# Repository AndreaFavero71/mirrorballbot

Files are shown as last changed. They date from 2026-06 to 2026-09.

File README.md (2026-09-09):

# MirrorBallBot

An open-source ball-balancing robot that sees through a mirror.<br><br>
MirrorBallBot keeps a ball centred on a circular platform by tilting it with three stepper motors.<br>
You can control the ball with your finger on a touchscreen, record paths, or let it auto-balance.<br>
MirrorBallBot is fully open-source:
 - two instruction manuals (QuickStartGuide and Reference Manual)
 - stl and step files
 - code

<br><br>
## Demo videos
https://youtu.be/ORftNl7bZG4<br><br>
Watch the Demo (https://youtu.be/ORftNl7bZG4)

<br><br>
https://youtu.be/C2Nf5jWF-SY<br><br>
Watch the Demo (https://youtu.be/C2Nf5jWF-SY)

<br><br>
Fully 3D printable version (smaller footprint):<br>
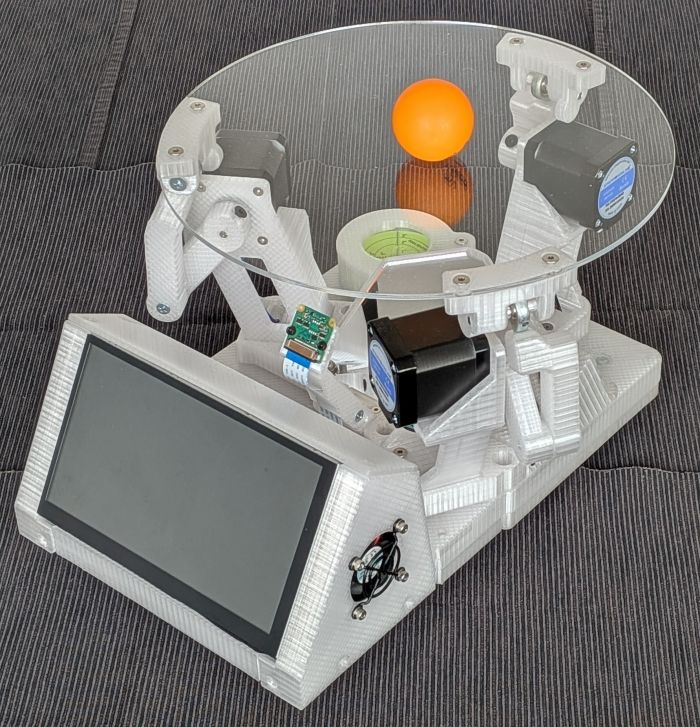
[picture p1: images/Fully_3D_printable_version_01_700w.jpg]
title image
 

<br><br>
## Key innovations
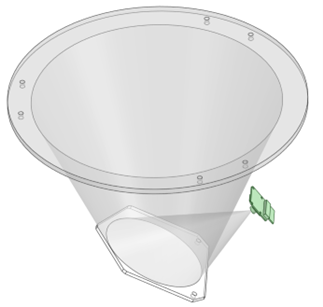
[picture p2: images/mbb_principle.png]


1. **Vision system**: Unlike most designs, it uses side-mounted camera pointing at a mirror (inclined 27°).
By considering the same camera and same robot height, the mirror concept increases the Field of View by 58%.
This allows for a larger platform while keeping the robot compact.

2. **Finger follower**: The ball follows, in real time, the finger's position on the touchscreen.

<br><br>
## Features

- **Two versions available:** Wooden base or fully 3D-printable.
- **Touchscreen GUI:** 7" DSI display with full control interface.
- **Real-Time Video Feed:** Live camera images displayed directly on screen.
- **Autonomous Auto-Balance:** Keeps the ball centred.
- **Finger-Follow Mode:** Drag your finger across the screen to guide the ball.
- **Predefined Paths:** Execute geometric patterns (Square, Circle, Infinity, Triangle, Line).
- **Record & Replay:** Draw custom paths with your finger to record and loop them.
- **Interactive PID Tuning:** Adjust control loop parameters via the GUI in real time.
- **Automatic HSV Calibration:** Instantly adapts to different ball colours and ambient lighting.
- **Sensorless Homing:** Uses TMC2209 StallGuard, no physical limit switches required.
- **Active Thermal Management:** PWM controlled cooling fans with automated temperature monitoring.

<br><br>
## How It Works
1. **Detection**: The camera looks at a mirror placed underneath the transparent platform, detects the ball via HSV thresholding, the ball position is retrieved. This flow works at more than 110 FPS.
2. **Calculation**: The ball position is compared to the target, and via a PID controller the new platform angle is calculated.
3. **Communication**: The Raspberry Pi 4 sends the information (speed and number of steps) to the three RP2040-Zero, via a custom I2C protocol.
4. **Actuation**: The three RP2040-Zero decode the I2C command to speed, direction and number of steps, and load them into the PIO buffer. Finally, the steppers move the platform. The platform actuation works at 17~25Hz.

<br><br>
### Architecture Overview
 - **Raspberry Pi 4:** Vision processing, PID control, GUI, and I2C Master.
 - **3x RP2040-Zero:** Motion execution, I2C Slaves, and hardware-precise PIO step generation.
 - **3x TMC2209:** Silent stepper drivers configured for Sensorless homing.
 - **3x NEMA17:** Stepper motors executing the platform tilts.

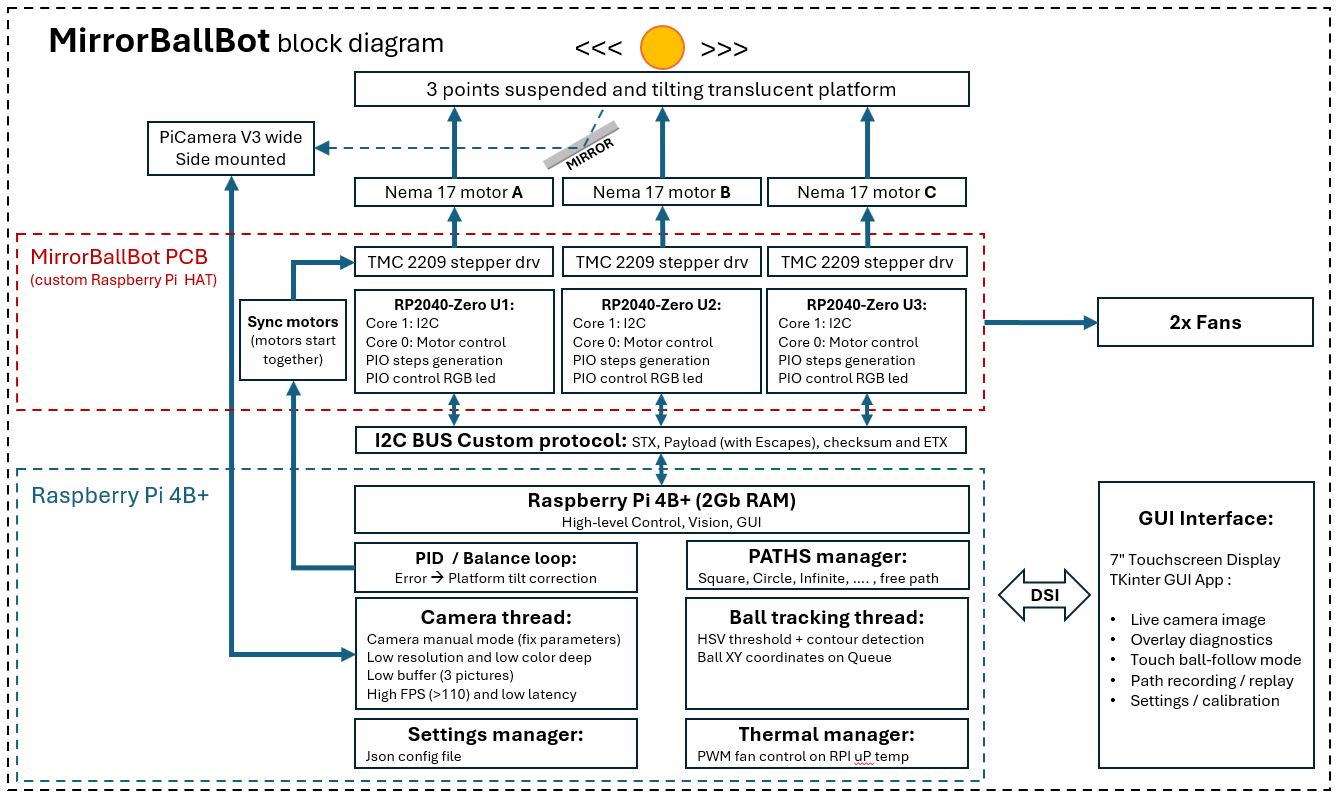
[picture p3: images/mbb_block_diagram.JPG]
block_diagram


<br><br>
## Hardware Requirements
| Component | Qty |
|---|-----|
| Raspberry Pi 4 2GB (1Gb is sufficient) | 1 |
| RP2040-Zero | 3 |
| TMC2209 stepper driver | 3 |
| NEMA17 stepper motor | 3 |
| PiCamera 3 Wide | 1 |
| 7" DSI touchscreen (800x480)| 1 |
| MirrorballBot custom PCB | 1 |
| XL4015 step-down converter | 1 |
| 20V 5A power supply | 1 |

> **Looking for the full Bill of Materials?** A comprehensive, itemized BOM with all the components and raw material specs is available in the full documentation.

<br><br>
## Documentation
The [Quick Start Guide](https://github.com/AndreaFavero71/mirrorballbot/blob/main/doc/MirrorBallBot_QuickStartGuide.pdf) provides the essential information to build the robot, as a PDF file of approx. 50 pages.<br>

The [Reference Manual](https://github.com/AndreaFavero71/mirrorballbot/blob/main/doc/MirrorBallBot_ReferenceManual.pdf) provides detailed information, yet the **~170 page PDF file** could intimidate at first glance. It provides exhaustive coverage of:
- BOM
- Wooden base or fully 3D printable version.
- 3D printing and acrylic laser cutting.
- PCB assembly & soldering maps (250+ pads).
- Detailed step-by-step mechanical assembly (36 steps with photos).
- Software environment setup and configuration parameters.
- GUI operation, PID tuning, and troubleshooting/QA.<br><br>

| Manual | Best for |
| :--- | :--- |
| **Quick Start Guide** | Most makers. It's concise, action-oriented, and will get you from zero to a working robot with minimal friction. |
| **Reference Manual** | When you want to understand *why* something works, encounter an issue not covered in the Quick Start Guide, or are curious about the design process, custom I2C protocol, or PID controller theory. |

**Recommendation:** Start with the Quick Start Guide. Follow the steps, and refer to the Reference Manual only when you need more detail.<br><br>
**Download the manuals from the [`/doc`](https://github.com/AndreaFavero71/mirrorballbot/blob/main/doc/) folder:**
- [Quick Start Guide (~50 pages)](https://github.com/AndreaFavero71/mirrorballbot/blob/main/doc/MirrorBallBot_QuickStartGuide.pdf)
- [Reference Manual (~170 pages)](https://github.com/AndreaFavero71/mirrorballbot/blob/main/doc/MirrorBallBot_ReferenceManual.pdf)

<br><br>
## Quick Start (for experienced makers)

1. Decide if wooden base or fully 3D-printed version. If wooden, CNC or route the base.
2. 3D print all parts (0.2mm layer, 30% infill, no supports, suggested PETG).
3. Laser cut acrylic (translucent plate + mirror).
4. Assemble the MirrorBallBot PCB (250+ solder pads).
5. Flash each RP2040-Zero with **MicroPython v1.24 Pimoroni Tiny2040** uf2 firmware (https://micropython.org/download/PIMORONI_TINY2040/).
6. Copy the MicroPython file to the RP2040-Zero boards (files at https://github.com/AndreaFavero71/mirrorballbot/tree/main/rp2040).
7. Set up the Raspberry Pi:
     - Flash a 32-bit Desktop OS (Trixie, or Bookworm) into a microSD.
      ```
      git clone https://github.com/AndreaFavero71/mirrorballbot.git
      cd mirrorballbot/src
      bash mbb_install.sh
      ```
8. Set the XL4015 voltage (OUT+) to 5.1V.
9. Set the drivers **Vref** according to the steppers' rated current.
10. Run first tests before full assembly; This includes checking the motor direction (it can be reversed via a settings in mbb_settings.json).
11. Full assembly following the step-by-step guide.
12. Calibrations:
     - Camera inclination (centre the camera view to the platform centre).
     - Sensorless homing calibration.
     - Ball colour calibration.
     - PID tuning.
13. Enjoy the robot!
14. Provide feedback :smile:

<br><br>
## First Run
After assembly, place the ball on the middle of the platform, and start the GUI via a Graphical Remote Desktop Client, like VNCViewer:
  ```
  cd ~/mirrorballbot/src
  python3 mbb_gui.py
  ```

Differently, just tap the MirrorBallBot icon on the 7-inch Raspberry Pi Desktop (the icon got automatically installed on the desktop, thanks to the mbb_install.sh).<br>

The GUI will open on the touchscreen.<br>
Auto-Balance should already be active, and the robot will start balancing the ball.<br>
If the ball is not wrapped by a green contour, set an indicative ball size and run the AUTO calibration for the colors.<br>

<br><br>
## Tools You'll Need
- 3D printer (Minimum 210x210 mm bed capacity).
- Laser cutter or CNC (for acrylic parts; commercial laser-cutting services work great).
- Hand router or CNC (for carving wire channels in the wood base), unless you prefer the fully 3D printable version.
- Soldering iron and basic electronics assembly tools.
- Multimeter (essential for driver Vref tuning).
- Screwdrivers and ball-end Allen keys.
- Computer with SD card reader.
- Solid foundational skills in DIY mechatronics and Python scripting.

<br><br>
## Sponsors
MirrorBallBot has been designed as an open-source project. This means I purchased most of the parts myself, just as anyone else would, and invested a considerable amount of time to make a fairly complex robot as easy as possible to reproduce.

I also greatly appreciate companies that support my hobby, by providing parts or services free of charge. The companies below generously sponsored components used in the MirrorBallBot project:
- Thanks to **PCBWay** for sponsoring the MirrorBallBot PCB [https://www.pcbway.com/]
- Thanks to **ELECROW** for sponsoring the 7" DSI touchscreen [https://www.elecrow.com/7-inch-800-480-dsi-display-touch-screen-with-bracket-compatible-with-raspberry-pi.html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]

I would also like to thank ELECROW and PCBWay for believing in this project. They both offered their support when MirrorBallBot was still just an idea, with no guarantee that it would ever reach the stage of becoming a published project.

<br><br>
## Credits
Credits to **danjperron** for his low-level I2C driver for RP2040, found at the Raspberry Pi forum (https://forums.raspberrypi.com/viewtopic.php?t=302978&start=50), from which I've derived the one used in this project.

<br><br>
## Feedback
If you decide to build your own MirrorBallBot, I would love to hear about it! Please open an issue, share your build photos, or submit feedback to let me know how your robot turned out.

<br><br>
## License
MIT License
[License: MIT](https://opensource.org/licenses/MIT) | [Python 3.9+](https://www.python.org/) | [MicroPython 1.24](https://micropython.org/)

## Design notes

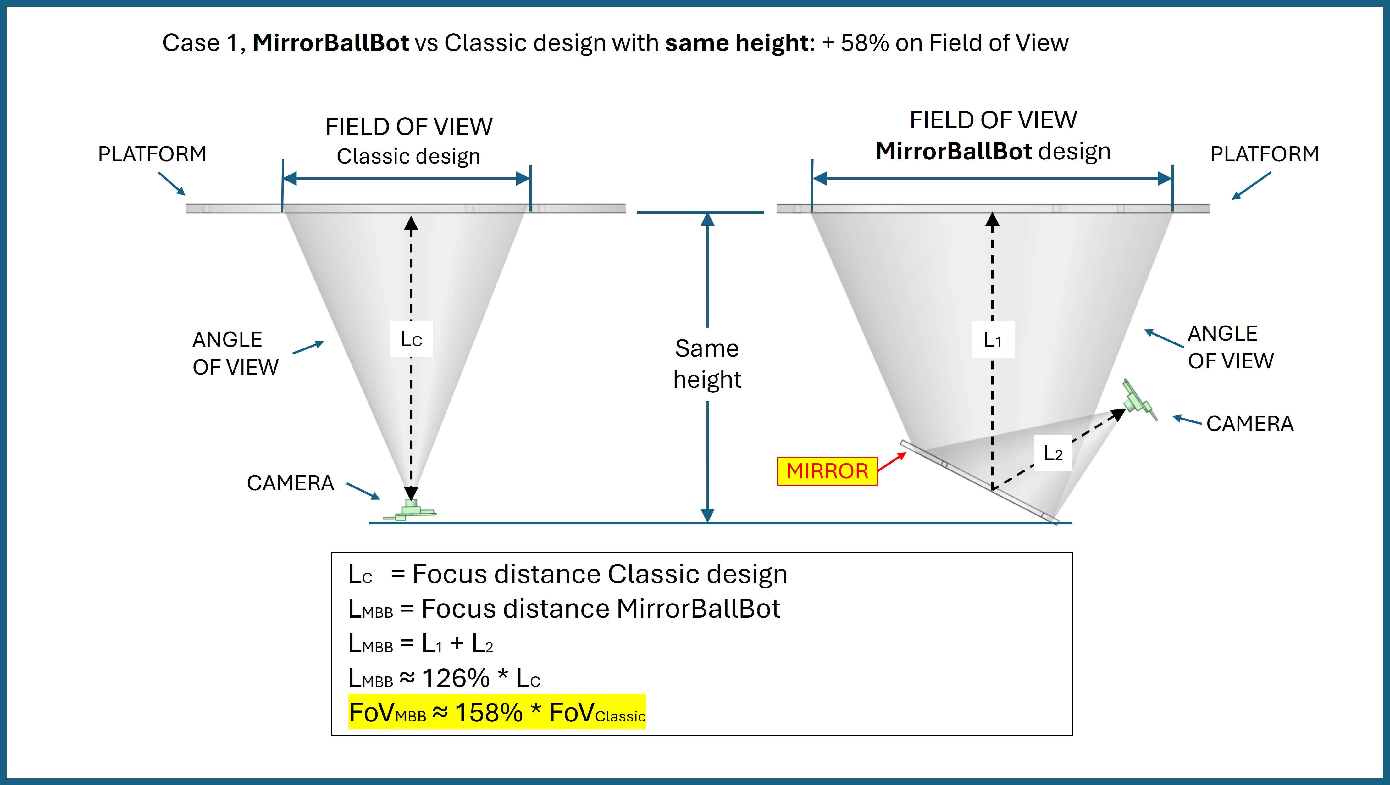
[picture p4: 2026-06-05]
images/Same_height_larger_FoV.jpg

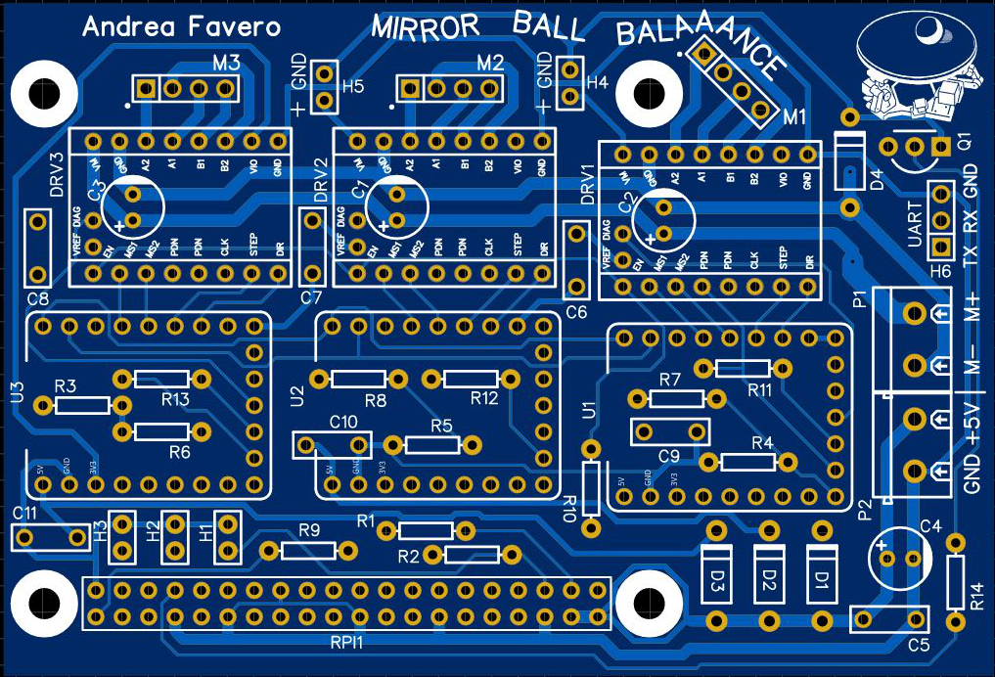
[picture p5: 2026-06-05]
board/Top_side.JPG

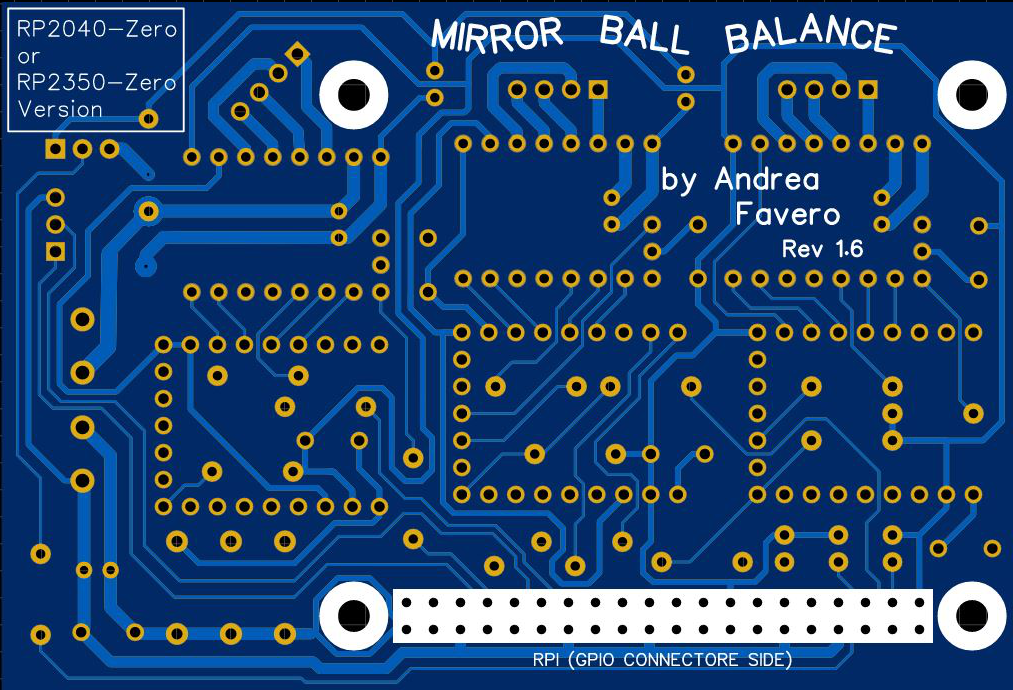
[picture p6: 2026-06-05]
board/Bottom_side.JPG

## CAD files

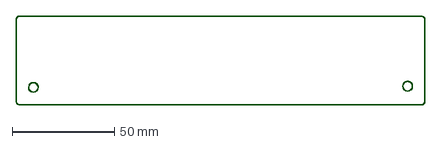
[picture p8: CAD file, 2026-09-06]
3d_models/fully_3d_printable/dxf/PCB_cover_3mm_thick.dxf
199.9 x 43.5 mm

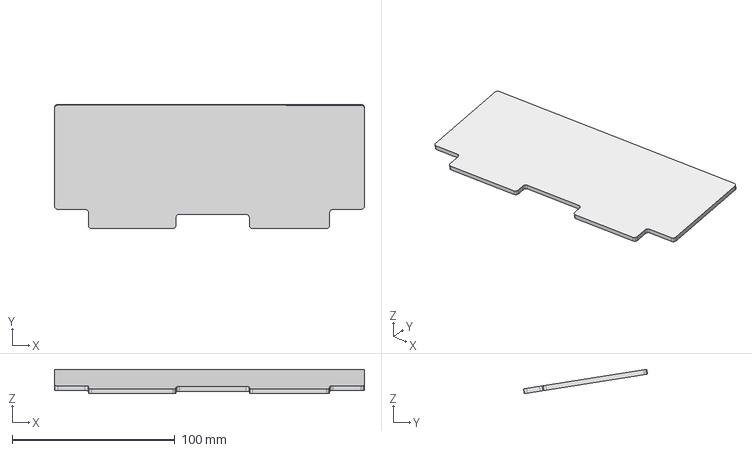
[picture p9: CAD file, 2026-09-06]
3d_models/fully_3d_printable/step/PCB_back_cover.stp
190.4 x 76.3 x 15.0 mm

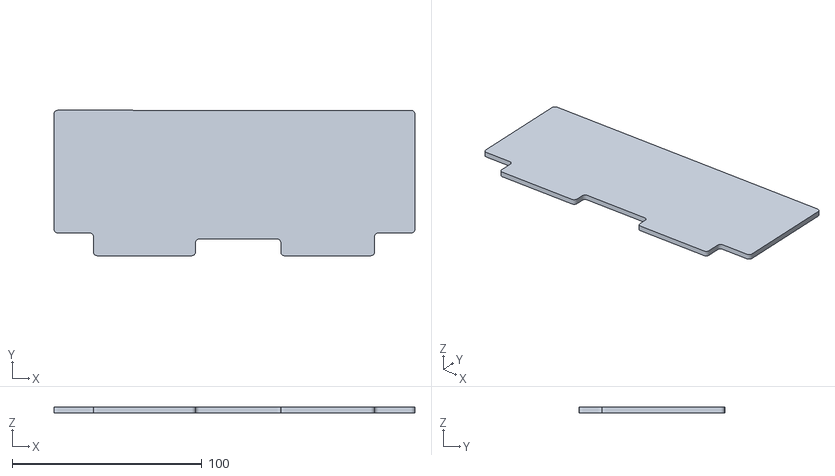
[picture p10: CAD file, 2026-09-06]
3d_models/fully_3d_printable/stl/PCB_back_panel.stl
190.4 x 76.8 x 3.00

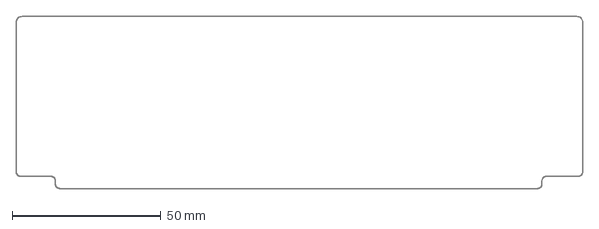
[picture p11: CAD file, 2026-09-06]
3d_models/wooden_base/dxf/PCB_back_cover_3mm_thick.dxf
190.4 x 57.8 mm

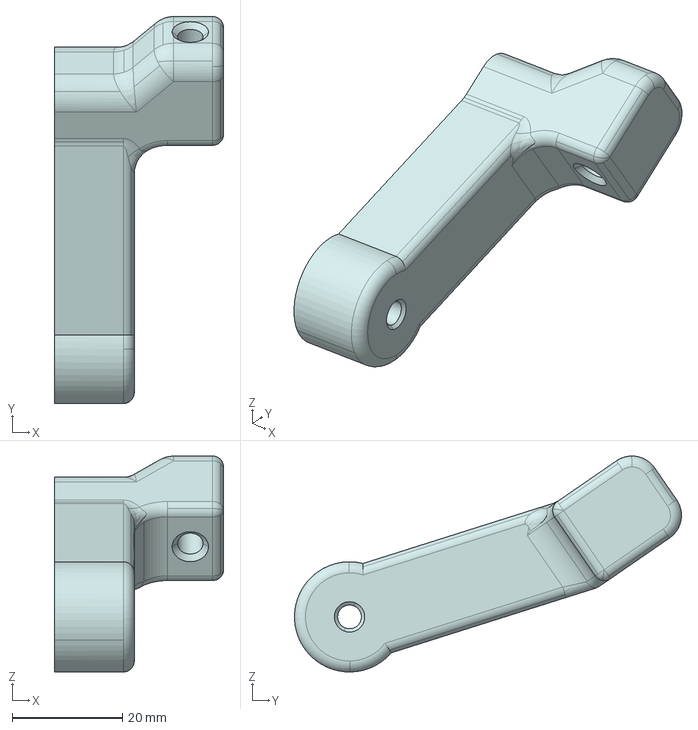
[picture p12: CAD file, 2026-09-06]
3d_models/wooden_base/step/Arm_2.stp
30.7 x 70.2 x 39.2 mm

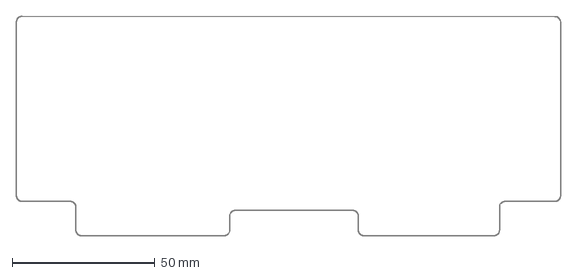
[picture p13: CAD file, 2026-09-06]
3d_models/fully_3d_printable/dxf/PCB_back_cover_3mm_thick.dxf
190.4 x 76.8 mm

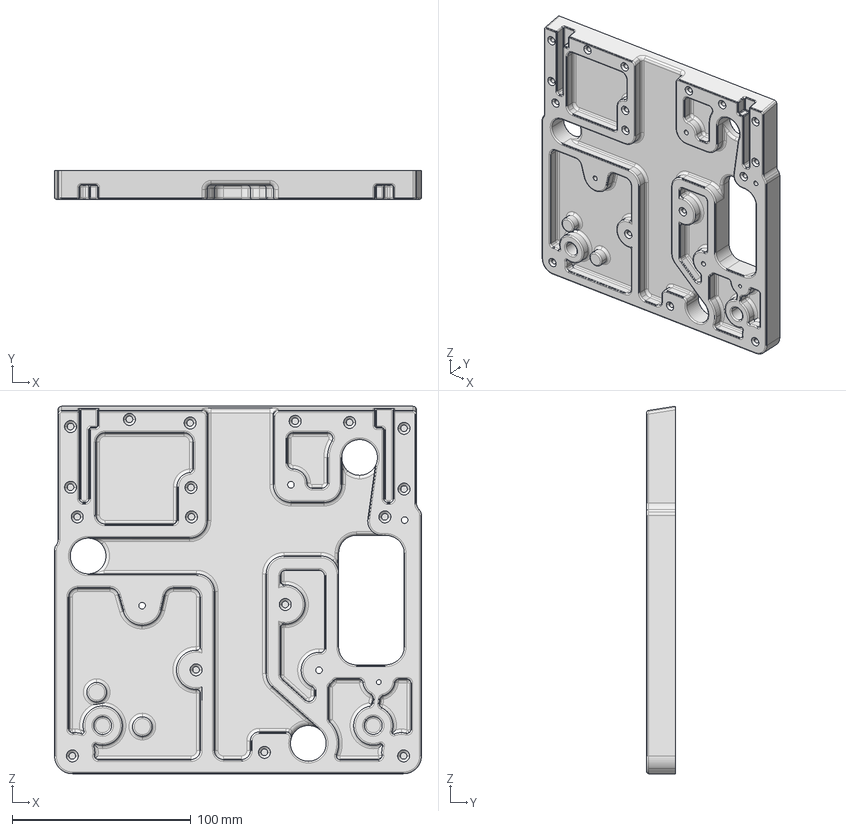
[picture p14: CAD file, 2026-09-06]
3d_models/fully_3d_printable/step/Base_top.stp
205.6 x 16.0 x 205.9 mm

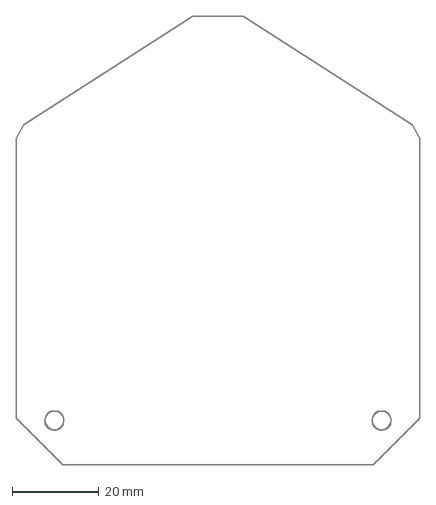
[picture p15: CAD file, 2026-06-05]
3d_models/wooden_base/dxf/Mirror.dxf
93.0 x 103.4 mm

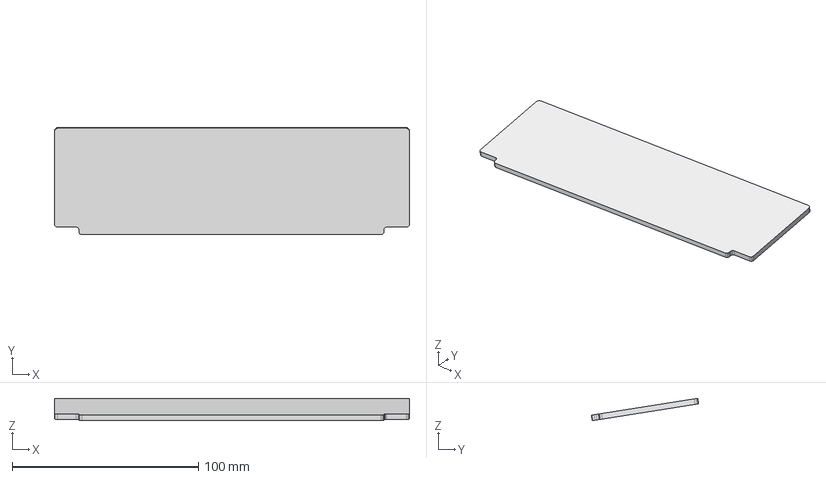
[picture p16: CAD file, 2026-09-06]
3d_models/wooden_base/step/PCB_back_cover.stp
190.4 x 57.6 x 12.0 mm

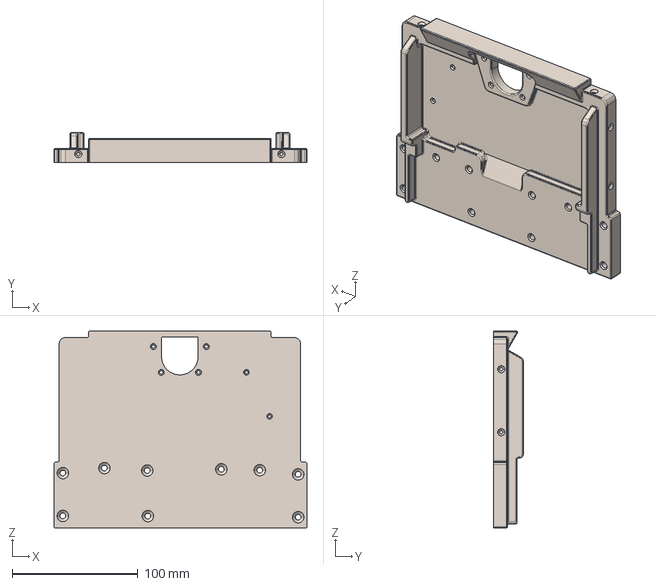
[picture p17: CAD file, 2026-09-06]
3d_models/fully_3d_printable/step/Base_bottom_F.stp
200.9 x 23.5 x 156.3 mm

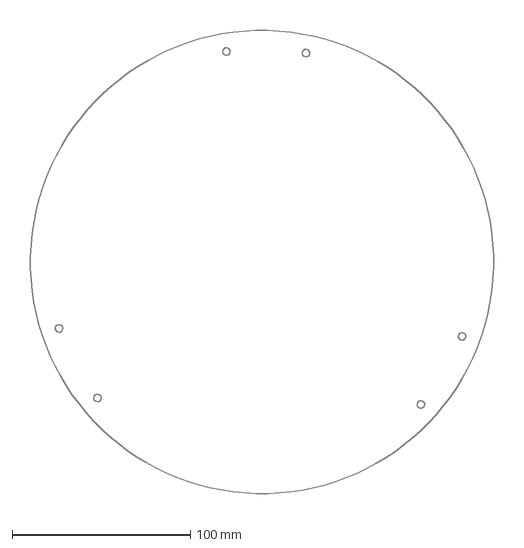
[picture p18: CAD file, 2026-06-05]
3d_models/wooden_base/dxf/Platform.dxf
275.9 x 275.9 mm

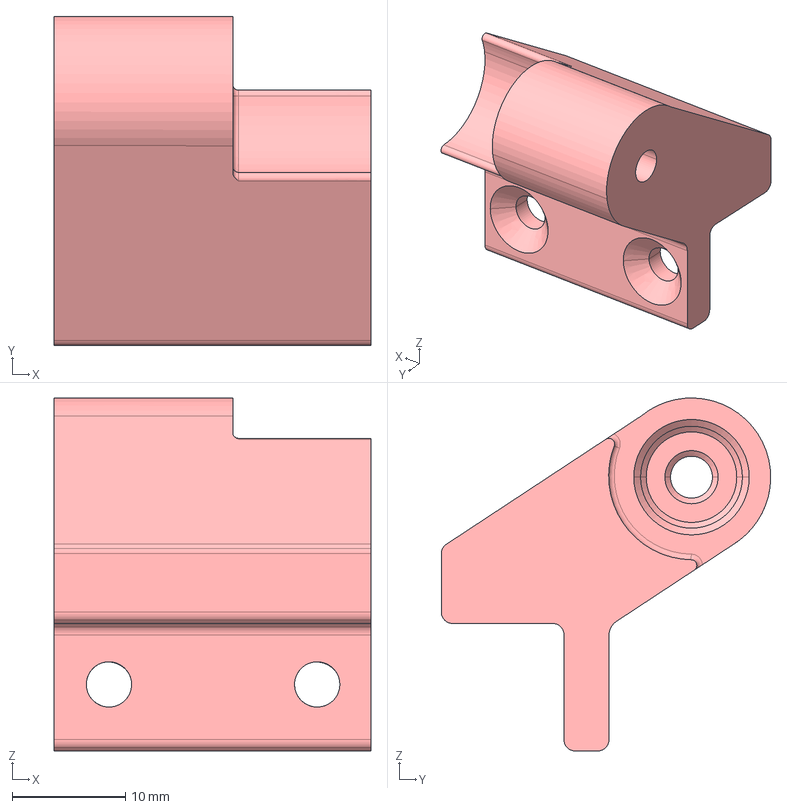
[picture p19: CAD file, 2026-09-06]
3d_models/wooden_base/step/Camera_holder_low.stp
28.0 x 29.1 x 31.2 mm

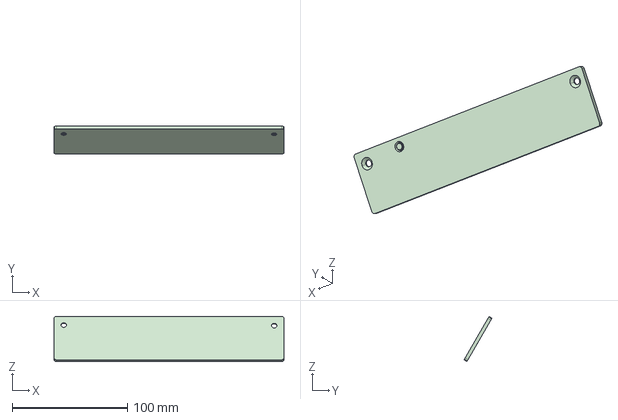
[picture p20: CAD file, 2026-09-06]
3d_models/fully_3d_printable/step/PCB_top_cover.stp
199.9 x 24.3 x 39.2 mm

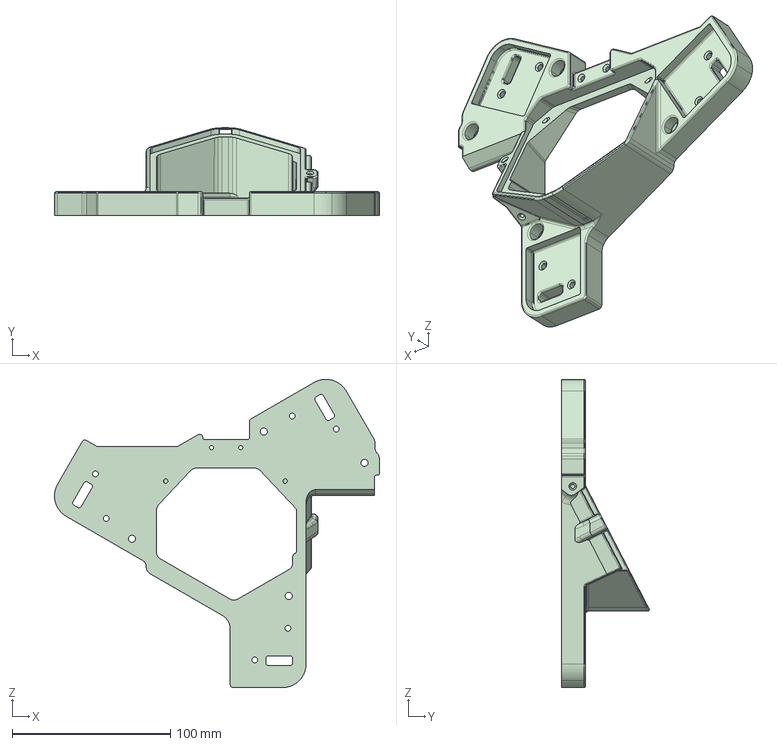
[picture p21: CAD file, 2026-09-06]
3d_models/wooden_base/step/Mirror_support.stp
205.5 x 55.4 x 194.9 mm

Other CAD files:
3d_models/fully_3d_printable/step/Label_neutral.stp
3d_models/wooden_base/step/Spirit_level_cover.stp
3d_models/fully_3d_printable/step/Arm_1.stp
3d_models/fully_3d_printable/step/Arm_2.stp
3d_models/fully_3d_printable/step/Base_bottom_R.stp
3d_models/fully_3d_printable/step/Camera_holder_low.stp
3d_models/fully_3d_printable/step/Camera_holder_top.stp
3d_models/fully_3d_printable/step/Front_foot_supp_M5.stp
3d_models/fully_3d_printable/step/Front_foot_supp_M6.stp
3d_models/fully_3d_printable/step/Front_foot_supp_M8.stp
3d_models/fully_3d_printable/step/Label_mbb.stp
3d_models/fully_3d_printable/step/Mirror_support.stp
3d_models/fully_3d_printable/step/Motor_support.stp
3d_models/fully_3d_printable/step/PCB_combined_cover.stp
3d_models/fully_3d_printable/step/Platform_support.stp
3d_models/fully_3d_printable/step/Power_in.stp
3d_models/fully_3d_printable/step/Rear_foot_supp_M5.stp
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

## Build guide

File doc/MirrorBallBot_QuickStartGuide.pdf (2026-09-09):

Andrea Favero, Groningen (NL)
09/09/2026 Rev 0 (always check if a newer version is available)

# MirrorBallBot - Quick Start Guide

## Build a ball-balancing robot that sees through a mirror

This is the Quick Start Guide, providing the essential information to build the MirrorBallBot.
For detailed explanations, theory, design philosophy, and troubleshooting, please refer to the full MirrorBallBot Reference Manual.

## Robot demonstration at YouTube: https://youtu.be/ORftNl7bZG4

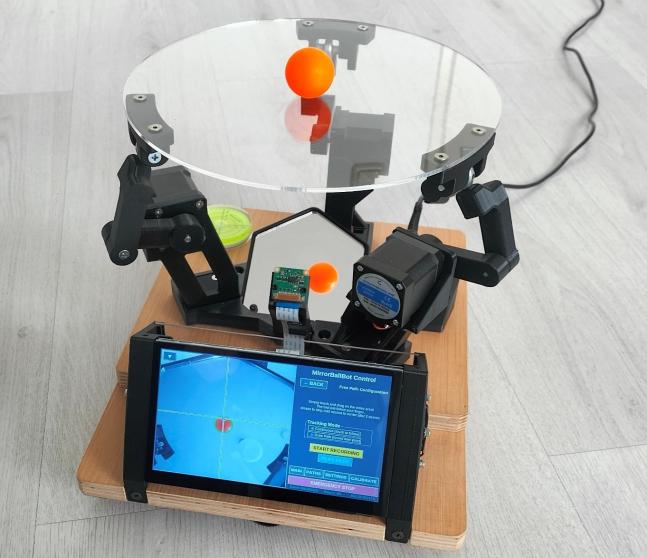
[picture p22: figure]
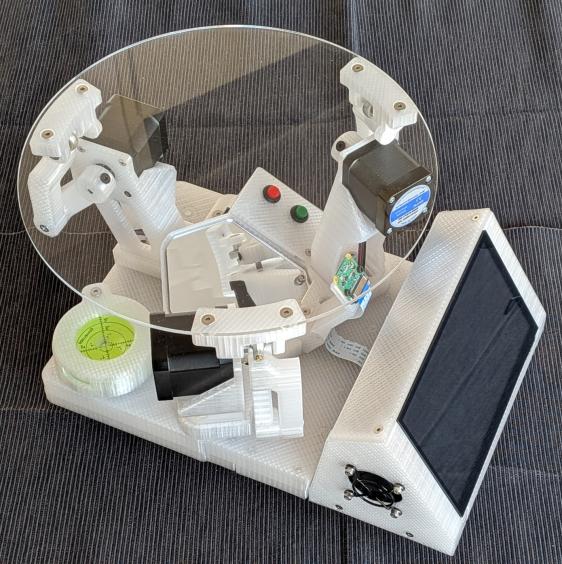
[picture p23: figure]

Wooden base version | Fully 3D printable version:

MirrorBallBot, Quick Start Guide

## 1. Table of contents

## 2.What is MirrorBallBot?

MirrorBallBot is a ball-balancing robot. It uses a camera, three stepper motors, and a clever mirror setup to keep a coloured ball balanced on a circular platform.
What it can do:
- Automatically balance the ball at the center of the platform
- Reject disturbances
- Move the ball to any position you choose
- Follow your finger on the touchscreen (real-time)
- Record and replay custom paths
- Execute predefined paths: square, circle, infinity, triangle, line

Two models available:
- Wooden base – my preference, heavier, dampens vibrations
- Fully 3D-printable – no woodworking required, fits a 210×210mm print bed

Project difficulty: 8/10 (using CUBOTino at 7/10 as a reference)

## 3. Two Instruction manuals

MirrorBallBot is documented in two complementary manuals:
Together, the two manuals serve different purposes:
Manual | Content | Pages
Quick Start Guide (this document) | Essential information to build the robot. Concise, action-oriented, step-by-step | ~ 50
Reference Manual | Detailed explanations, theory, design philosophy, troubleshooting, Q&A and much more. It also includes the assembly steps, with several pictures and detailed information. | ~ 170

Which manual should you use?
Start with the Quick Start Guide. It will get you from zero to a working robot with minimal friction. Follow the steps, and refer to the Reference Manual only when you need more detail. Use this Reference Manual when: you want to understand why something works, you encounter an issue not covered here, or you're curious about the design process, the custom I2C protocol, or the PID controller theory.

## 4.Block diagram

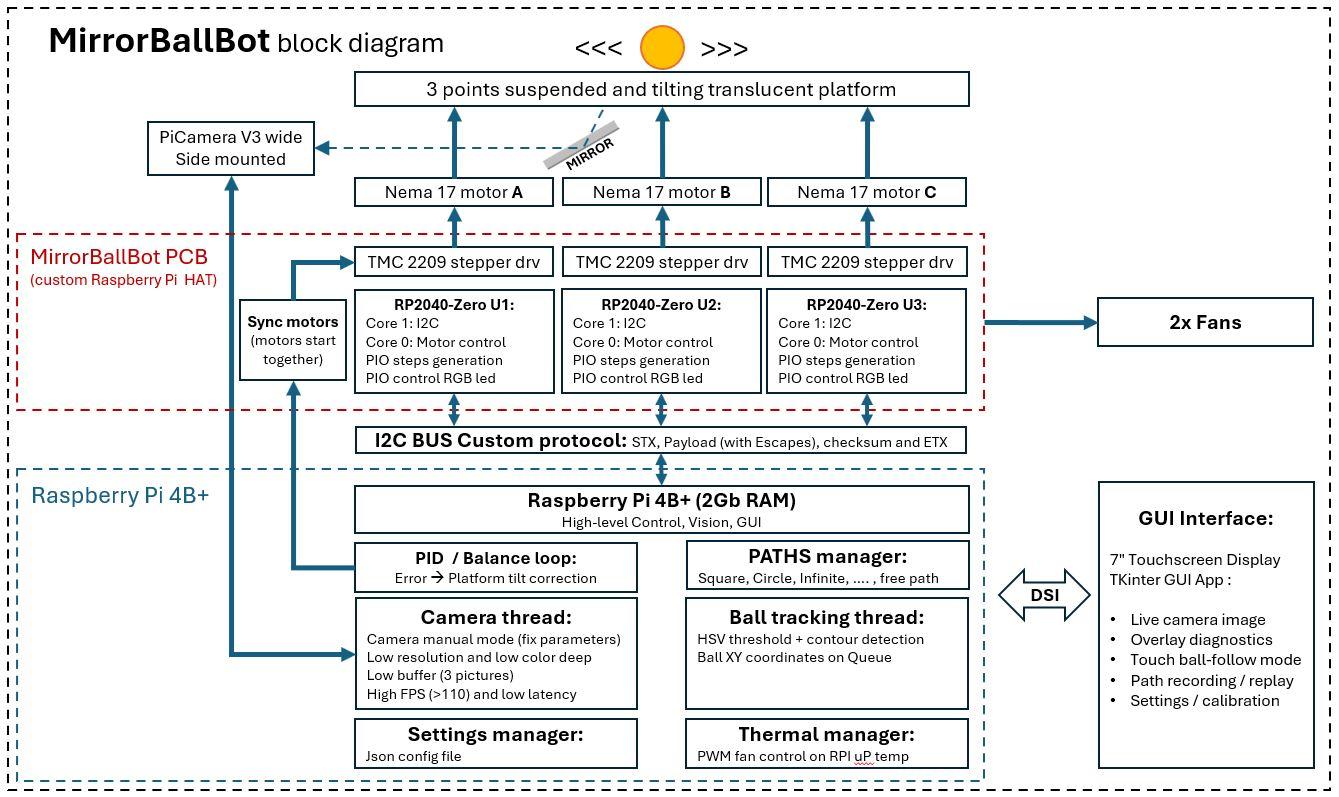
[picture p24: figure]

Page 6

Modules connections diagram

## 5.Safety disclaimer

Energize the robot only via a power supply having class 2 insulation from the Mains. Chargers for laptops normally have this safety feature: Check it for your own safety. Despite the robot mechanical force is limited, it must be operated only under adult supervision.
If you build and use a robot, based on this information, you accept it is on your own risk.

## 6.What you'll need

Estimated Time

Task | Time Estimate
3D printing (wooden version / fully 3D version) | 2 days / 4 days
Wood base preparation (if applicable) | ½ - 1 day
PCB soldering | ½ day
Programming & testing | ½ day
Assembly | ½ day
Tuning & calibration | A few hours to a few days
Total | ~2-3 weeks

Cost: Approximately €300 in materials (spring 2026 prices).
Tools Required
- 3D printer (210×210mm bed minimum), or access to one
- Laser cutter (for acrylic platform and mirror) or access to one
- (Optional) Router or CNC for wooden base version
- Soldering iron and basic soldering skills
- Multimeter
- Screwdrivers (Phillips, flathead, Allen keys)

## 7.BOM

Ref | Description | Link | Cost (Euro)
1 | Raspberry Pi 4 (2Gb or 1Gb RAM) | https://www.raspberrypi.com/products/raspberry-pi-4-model-b/ (https://www.raspberrypi.com/products/raspberry-pi-4-model-b/) | 70
2 | PiCamera V3 wide (12Mp, not the NoIR) | https://www.raspberrypi.com/products/camera-module-3/ (https://www.raspberrypi.com/products/camera-module-3/) | 40
3 | MicroSD 16Gb Class 10 (Speed is only relevant for the OS flashing, not for the robot operation) | Avoid cards with low ratings | 10
4 | Ribbon cable (15pins 30cm) | https://tinyurl.com/ssehw7 dh (https://tinyurl.com/ssehw7dh) | 4.5
5 | Stepper motors (42x42x48mm, 1.8deg/step, 2A, ca50Ncm, shaft Ø5.0mm, D-cut 15mm) | https://tinyurl.com/mr2fmd mp (https://tinyurl.com/mr2fmdmp) | 30
6 | Stepper drivers (TMC 2209 V1.3) | https://tinyurl.com/yjtc4p3f | 15
7 | Stepper motor controller (RP2040-Zero) | https://tinyurl.com/myztcu kk (https://tinyurl.com/myztcukk) | 4.5
8 | MirrorBallBot PCB | https://www.pcbway.com/ | 5
9 | Display Elecrow 7" 800x600 DSI touchscreen | https://www.elecrow.com/7-inch-800-480-dsi-display-touch-screen-with-bracket-compatible-with-raspberry-pi.html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 (https://www.elecrow.com/7-inch-800-480-dsi-display-touch-screen-with-bracket-compatible-with-raspberry-pi.html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) | 40
10 | Brushless fan 40x10mm 24Vdc | https://tinyurl.com/2zf8nw 3h (https://tinyurl.com/2zf8nw3h) | 9.4
11 | Fans’ grids | https://tinyurl.com/yznzz6f p (https://tinyurl.com/yznzz6fp) | 5.5
12 | Step-down power supply (XL4015 adjustable 4-35V) | https://tinyurl.com/26f39us a (https://tinyurl.com/26f39usa) | 2.7
13 | Spheric-joints (SA5T/K Rod End Bearing, 4pcs 5mm Metric Male Thread) | https://tinyurl.com/3jdnu4 5t (https://tinyurl.com/3jdnu45t) | 3

Ref | Description | Link | Needed Q.ty
14 | Acrylic (Plexiglass) translucent plate to laser cut Ø26cm. 3mm thick for balancing, 6mm thick for bouncing | https://tinyurl.com/2m9ttb z6 (https://tinyurl.com/2m9ttbz6) | 1
15 | Acrylic (Plexiglass) mirror 2.5mm to laser cut (Self-adhesive types are easy to source) | https://tinyurl.com/bdeua bmh (https://tinyurl.com/bdeuabmh) | 1
16 | Push button (12mm momentary push button) | https://tinyurl.com/36j3m 7ru (https://tinyurl.com/36j3m7ru) | 2
17 | Standoff screws (M2.5mm x 15mm x 6mm) | https://tinyurl.com/t3c636 ns (https://tinyurl.com/t3c636ns) | 4
18 | Plywood 18mm unless you prefer the fully 3D printable version | Check at your local wood/ hardware store | 1 panel (60x60 cm)
19 | Adjustable feet (thread from M5 to M8) | Check at your local hardware store | 3
20 | Spirit level Ø60mm | https://tinyurl.com/ukpsd 8r7 (https://tinyurl.com/ukpsd8r7) | 1
21 | PETG Filament (~1.1Kg if you prefer the fully 3D printable version) | Your usual filament supplier | ~0.55 Kg (~1.1 Kg)
22 | Plastic's ball (suggested orange, Table football balls Ø30 ~ 35mm, 17~25 grams) | https://tinyurl.com/yc8a9 b4n (https://tinyurl.com/yc8a9b4n) | 1
23 | Power supply 20V 5A (I used a spare power supply from a HP laptop) | https://tinyurl.com/58j5st 68 (https://tinyurl.com/58j5st68) | 1
24 | Power socket (in my case one compatible with the HP power supply: Computer Adapter Cable Converter Cable 7.4x5mm Female to 5.5x2.5mm Male for Laptop) | https://tinyurl.com/bdz3c auv (https://tinyurl.com/bdz3cauv) | 1

Notes:
1. The reference to amazon.com are used as it might offer more accurate description and pictures of the products, as well as a cost reference.
2. I personally buy many parts from Aliexpress.com and other shops, also Amazon.nl, yet not necessarily a convenient choice.

Components for the PCB (all for through hole assembly)

Component | Type | Quantity
Resistors (1/4 W) | 470 Ω | 6
| 1 KΩ | 4
| 10 KΩ | 4
Diodes | 1N5818 (or 1N5819) | 4
Capacitors | 100~220uF 35V electrolytic | 4
| 10uF 30V ceramic | 7
Transistor | BC337 | 1
Male header 2.54mm | 2 pins | 5
| 3 pins | 1
| 4 pins | 3
Female headers 2.54mm | 2pins | 3
| 7pins | 3
| 8pins | 12
Screw connectors 5.08mm | 2 poles | 2
2x20 Female header extra height | For Raspberry Pi 4, with 5.08mm additional spacer (taller version) | 1

Screws list for the wooden base version
Screw (alternative screw) | Screw head | total | Thread
2x10mm (2.5x10mm) | flat | 2 | for wood
3,5x16mm (3,5x20mm) | conical | 14
3,5x30mm (3,5x25mm) | conical | 5
M2.5x6mm | flat | 10 | Metric
M3x10mm (M3x12mm) | flat | 2
M3x20mm (M3x25mm) + washers + nuts | flat | 8
M3x10mm (M3x8mm) | conical | 12
M3x10mm (M3x12mm) | conical | 4
M4x12mm (M4x16mm) | conical | 16
M4x20mm ((M4x25mm) | conical | 1
M4x30mm (M4x25mm) | conical | 3
M5x40mm (M5x35mm) | Conical | 3

Screws list for the fully 3D printable version
Screw (alternative screw) | Screw head | total | Thread
M2,5x6mm | Flat | 10 | Metric
M2,5x8mm (M2.5x10mm) | Flat | 2
M3x10mm (M3*12mm) | Flat | 2
M3x10mm (M3*8mm) | Conical | 12
M3x10mm (M3*12mm) | Conical | 24
M3x20mm (M3x25mm) + washers + nuts | Flat | 8
M4x12mm (up to max M4x20mm) | Conical | 18
M4x20mm (M4x16mm) | Conical | 6
M4x25mm (M4x20mm) | Conical | 18
M4x30mm (M4x25mm) | Conical | 3
M5x40mm (M5x35mm) | Conical | 3

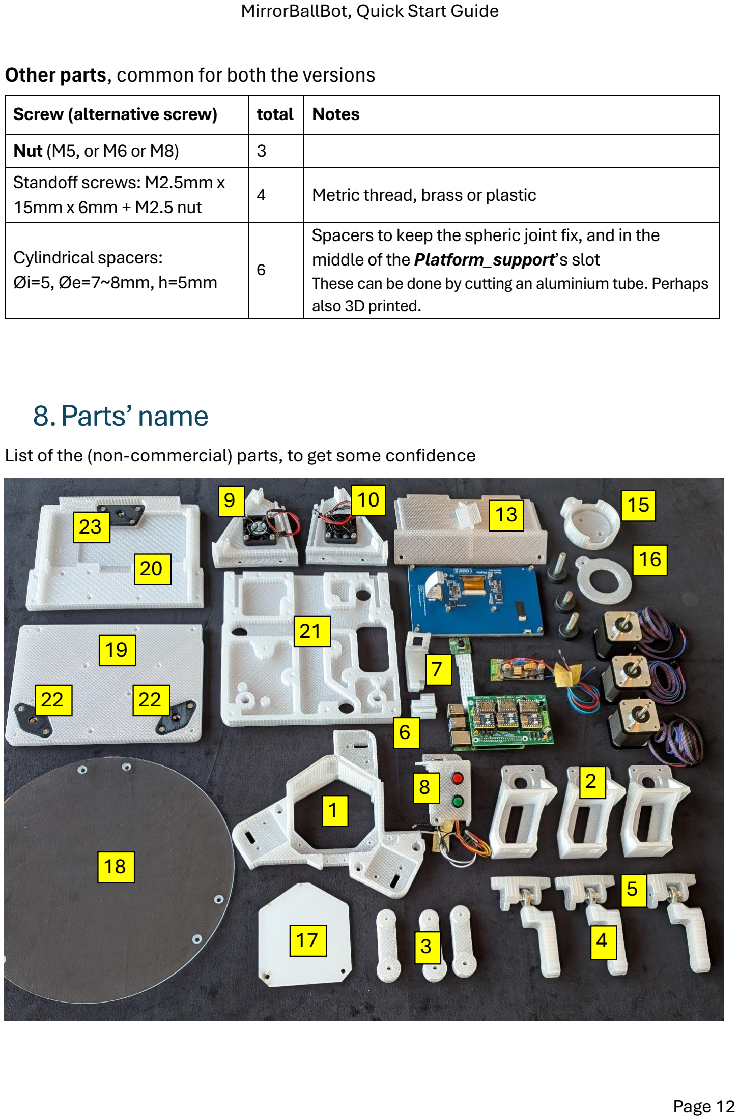
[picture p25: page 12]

Other parts, common for both the versions

Screw (alternative screw) | total | Notes
Nut (M5, or M6 or M8) | 3
Standoff screws: M2.5mm x 15mm x 6mm + M2.5 nut | 4 | Metric thread, brass or plastic
Cylindrical spacers: Øi=5, Øe=7~8mm, h=5mm | 6 | Spacers to keep the spheric joint fix, and in the middle of the Platform_support’s slot These can be done by cutting an aluminium tube. Perhaps also 3D printed.

## 8.Parts’ name

List of the (non-commercial) parts, to get some confidence

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
9 | 10
13 | 15

16

17

18

19

20

21

22 22

23

For both versions

Ref | Part name | Short description
1 | Mirror_support | Supports the Mirror, Motor_supports, Camera_holder_low, Power_in
2 | Motor_supports | Support the stepper motors
3 | Arm_1 | Arm connected to the motor shaft
4 | Arm_2 | Arm connected to the Arm_1
5 | Platform support | Part in between Arm_2 and the Platform
6 | Camera_holder_low | Supports the Camera_holder_top
7 | Camera_holder_top | Supports the PiCamera
8 | Power_in | Support the pushbuttons the power connector
9 | Supp_Rpi_L | Left support for Display and electronic
10 | Supp_Rpi_R | Right support for Display and electronic
11 | PCB_top_cover | Top panel closing the electronic case (laser cut of 3D printed)
12 | PCB_back_cover | Back panel closing the electronic case (laser cut of 3D printed)
13 | PCB_combined_cover | 3D printed cover closing the top and the back
14 | Label_mbb or Label_neutral | Aesthetic part
15 | Spirit_level_holder | Supports the spirit level and its cover
16 | Spirit_level_cover | Retains the spirit level
17 | Mirror
18 | Platform

Specific parts for Fully 3D printable version
Ref | Part name | Short description
19 | Base_bottom_R | The bottom base with the Rear feet
20 | Base_bottom_F | The bottom base with the Front foot
21 | Base_top | The smaller base, that stays above the Base_bottom_R and Base_bottom_F
22 | Rear_foot_support_Mx | Part holding the nut for the rear feet. Mx can be M5, M6 or M8
23 | Front_foot_support_Mx | Part holding the nut for the front foot. Mx can be M5, M6 or M8

Specific parts for the wooden base version
Part name | Short description
Wooden_base_bottom | The largest wooden base, holding the feet
Wooden_base_top | The smaller wooden base, that stays above the Wooden_base_bottom
PCB_front_cover | Aesthetic part flashing the Display’s bottom edge

## 9.Where to get files

All files are available on GitHub: https://github.com/AndreaFavero71/MirrorBallBot

Version | Folder /3d_models/wooden_base/stl | Contents Wooden base 3D printable parts
| /3d_models/wooden_base/dxf | Laser cutting files (platform and mirror)
| /3d_models/wooden_base/stp | 3D editable files
| /3d_models/wooden_base/pdf | 2D drawing for the wooden base preparation
| /3d_models/wooden_base/complete_robot | Step file for the complete robot
| /3d_models/fully_3d_printable/stl | 3D printable parts for fully 3D version
| /3d_models/fully_3d_printable/dxf | Laser cutting files
| /3d_models/fully_3d_printable/stp | Step file for the complete robot
| /3d_models/ fully_3d_printable /complete_robot | Step file for the complete robot
| /board | PCB Gerber files and schematic PDF
| /src | Python code for Raspberry Pi 4
| /rp2040 | MicroPython code for RP2040-Zero boards
| /doc | Manuals

### Fully 3D

### printable

Both

## 10. Build steps

This is the complete build checklist. Each step is detailed in the following chapters.

Step | What to Do
1 | Choose your model (wooden base or fully 3D-printable)
2 | 3D print all parts (30% infill, no supports, 0.2mm layer, suggested PETG)
3 | Laser cut the acrylic platform and mirror
4 | Prepare the base (woodworking or 3D printing)
5 | Assemble the MirrorBallBot PCB
6 | Prepare the Power_in box with socket and buttons
7 | IMPORTANT: Calibrate XL4015 to 5.1V BEFORE connecting to PCB
8 | Flash all three RP2040-Zero boards with MicroPython v1.24
9 | Set up Raspberry Pi 4 (flash OS, clone repo, run installer)
10 | Run first tests (motors, fans, camera) – set TMC2209 Vref
11 | Assemble the complete robot (follow assembly table)
12 | Tune sensorless homing and platform levelling
13 | Calibrate ball color (use AUTO calibration in GUI)
14 | Tune PID settings (start with Kp=1.3, Ki=0, Kd=1.0)
15 | Test predefined paths (square, circle)
16 | Try freehand finger-following on the touchscreen
17 | Enjoy your MirrorBallBot!

## 11. Choose your model

MirrorBallBot is available in two versions. Choose before you start 3D printing, as some parts differ between models.

Feature | Wooden Base (my preference) | Fully 3D-Printed Base
Construction | Two layers of 18mm plywood (CNC or manual router) | Fully 3D printed, split to fit 210×210mm beds
Robot weight | 4.2 kg | 3.1 kg
Pros | Heavier = dampens vibrations, classic aesthetic | No woodworking required, fully 3D printable
Cons | Requires woodworking tools or CNC | Doubling the 3D printing time
Filament needed | ~550g (PETG) | ~1100g (PETG)

My recommendation:
- Wooden base If you enjoy woodworking and have the tools
- 3D-printed base If you don't have woodworking tools or want it fully 3D printed

Important: STL files are in separate folders (/wooden_base/stl and /fully_3d_printable/stl). Do not mix files between versions.

## 12. 3D printing

Material: PETG is recommended for its balance of strength and flexibility. It also doesn't degrade over time or from UV light.

Settings I used on my Ender 3 printer

Parameter | Setting
Layer height | 0.2 mm
Infill | 30% (essential for screw boss strength)
Supports | None (all parts designed to print support-free)
Bed temperature | 82°C
Nozzle temperature | 254°C
Vertical shells | 2
Horizontal layers | 3

Printing Time Reference (Ender3)

Version | Total Filament | Total Time
Wooden base | ~500g | ~46 hours
Fully 3D-printable | ~1173g | ~93 hours
Note: These times are for reference. Your printer may be faster or slower.

Files

Version | STL Files
Wooden base | /3d_models/wooden_base/stl
Fully 3D-printable | /3d_models/fully_3d_printable/stl
Version | STL Files

For editable files (STEP format), check the /step folders in the repository.
The complete robot, for both versions, is also available in the /complete_robot folders in the repository. This might be of interest for those who’d like deriving their own version.

## 13. Prepare the acrylic parts (Laser Cutting)

Materials
Part | Material | Thickness
Platform | Translucent acrylic/Plexiglass | 3mm (balancing) or 6mm (bouncing)
Mirror | Acrylic mirror with self-adhesive backing | 2.5mm

Cutting Specifications
Part | Specification
Platform | Outer diameter 260mm, 6 holes Ø4.5mm (from DXF file)
Mirror | Cut to size (DXF file provided)

After Cutting
1. Chamfer the 6 holes in the platform with a chamfering drill bit
2. Remove protective film from both sides of the platform
3. Peel the mirror's protective film (after assembly)

Files
Version | DXF Location
Wooden base | /3d_models/wooden_base/dxf
Fully 3D-printable | /3d_models/fully_3d_printable/dxf

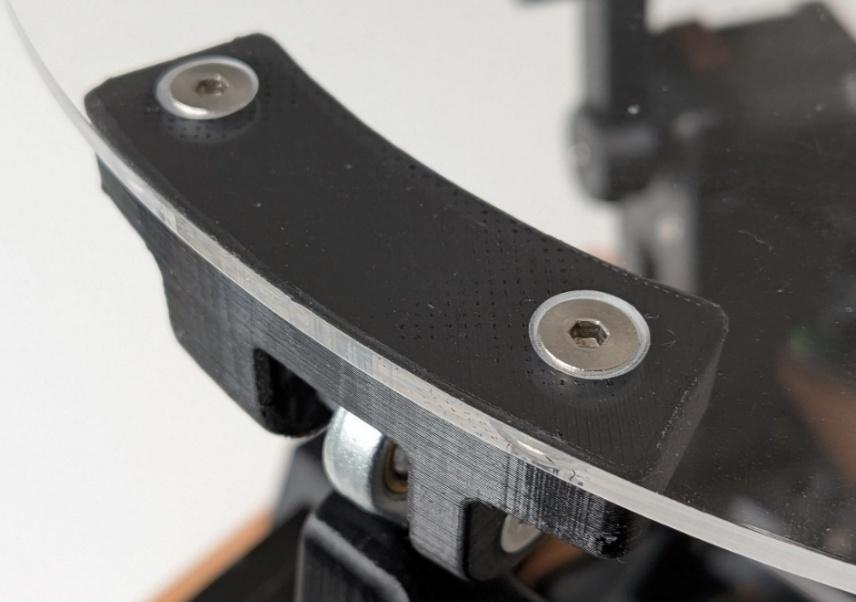
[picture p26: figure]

## 14. Prepare the Base

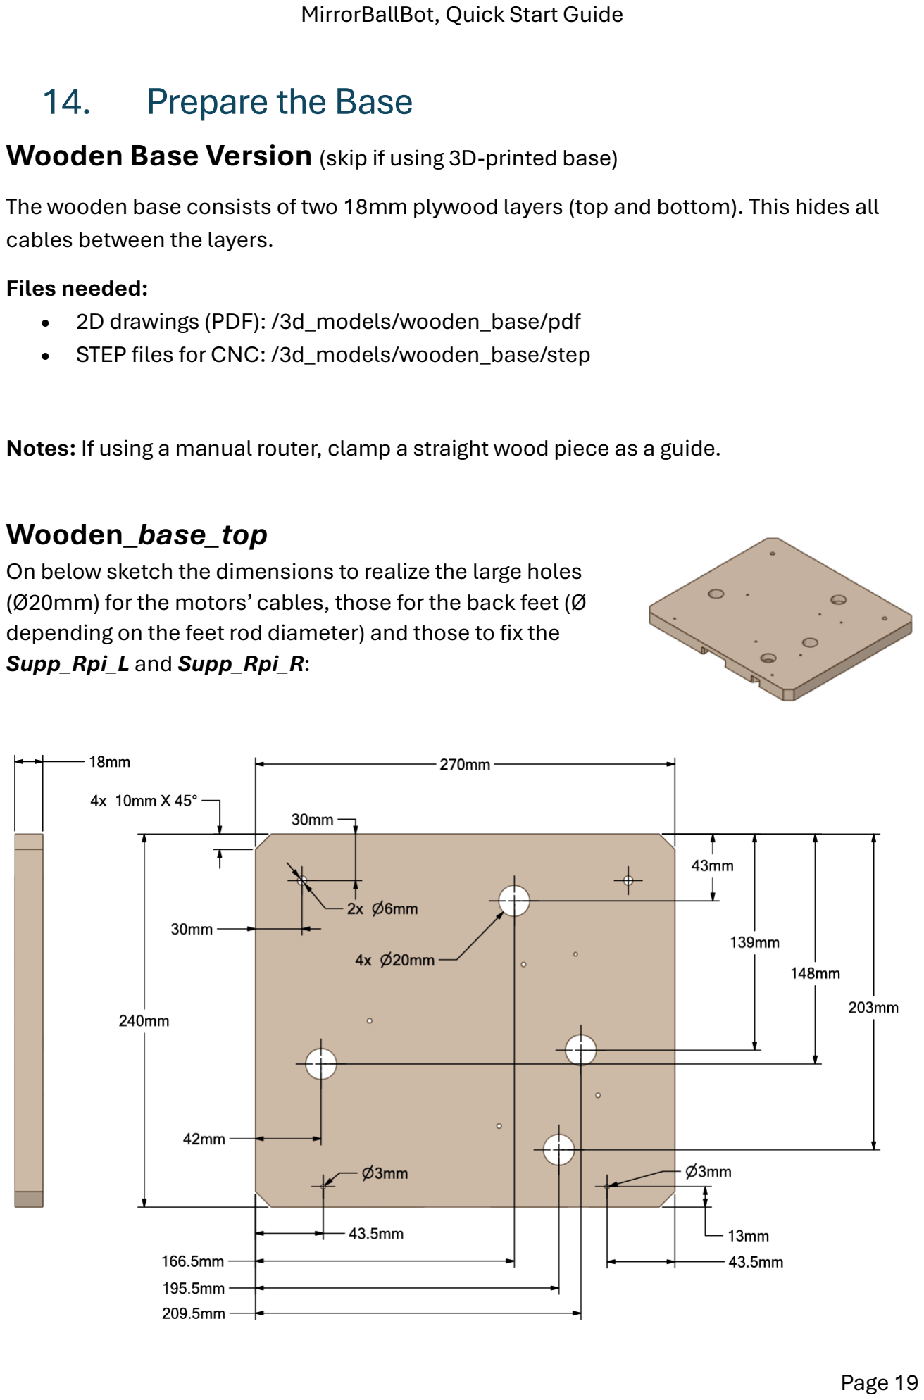
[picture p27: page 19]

Wooden Base Version (skip if using 3D-printed base)

The wooden base consists of two 18mm plywood layers (top and bottom). This hides all cables between the layers.
Files needed:
- 2D drawings (PDF): /3d_models/wooden_base/pdf
- STEP files for CNC: /3d_models/wooden_base/step

Notes: If using a manual router, clamp a straight wood piece as a guide.

## Wooden_base_top

On below sketch the dimensions to realize the large holes
(Ø20mm) for the motors’ cables, those for the back feet (Ø depending on the feet rod diameter) and those to fix the Supp_Rpi_L and Supp_Rpi_R:

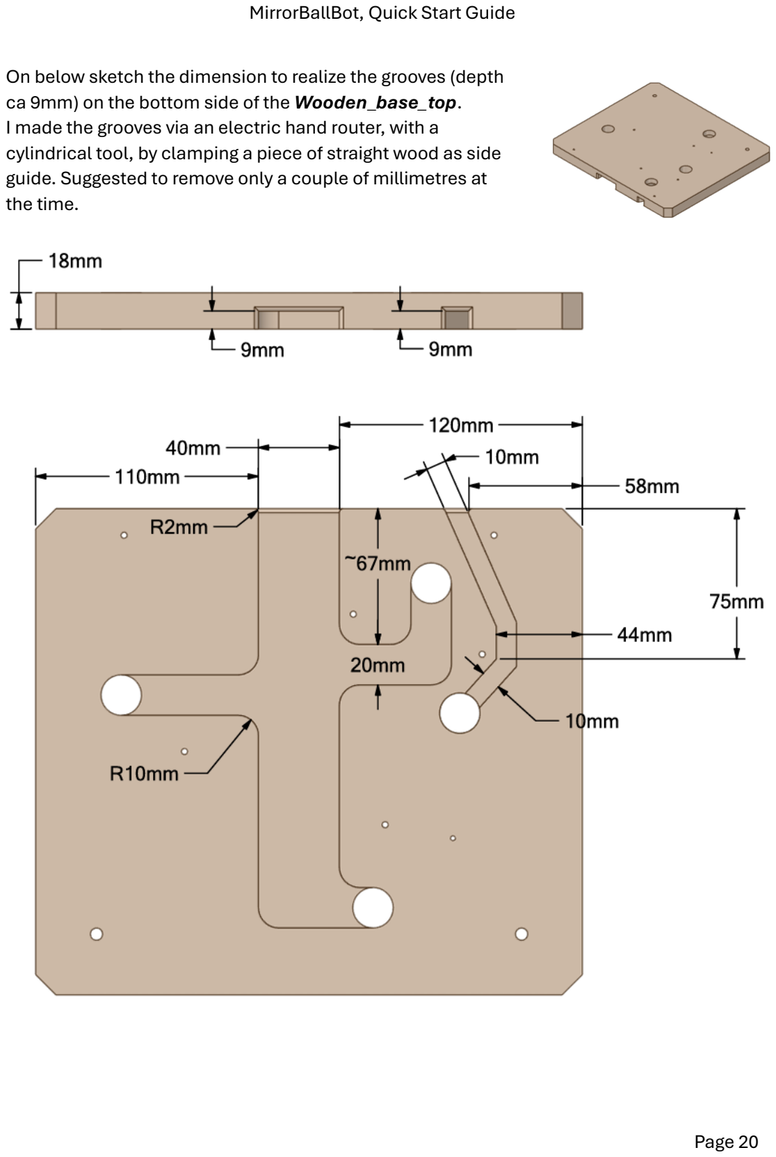
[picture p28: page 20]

On below sketch the dimension to realize the grooves (depth ca 9mm) on the bottom side of the Wooden_base_top.
I made the grooves via an electric hand router, with a cylindrical tool, by clamping a piece of straight wood as side guide. Suggested to remove only a couple of millimetres at the time.

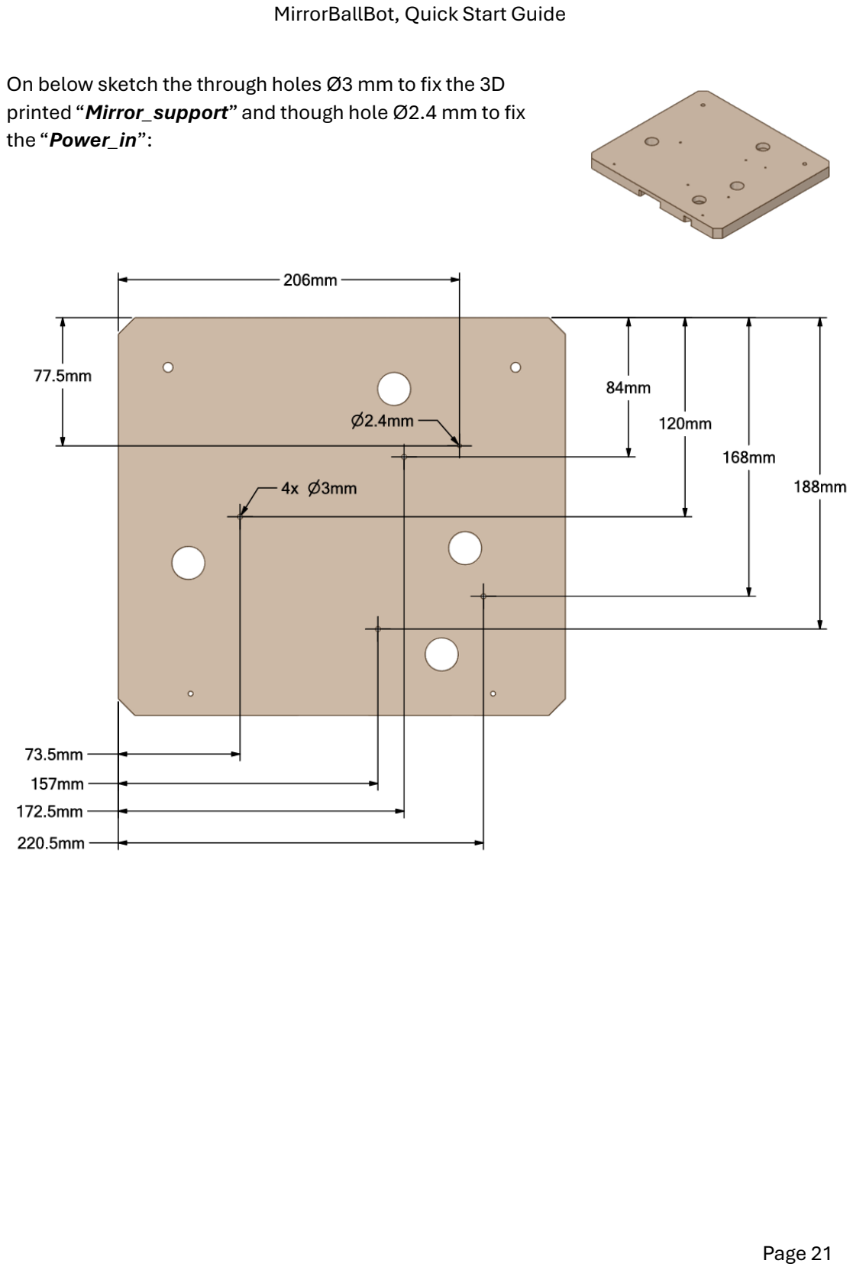
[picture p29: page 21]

On below sketch the through holes Ø3 mm to fix the 3D printed “Mirror_support” and though hole Ø2.4 mm to fix the “Power_in”:

## Wooden_base_bottom:

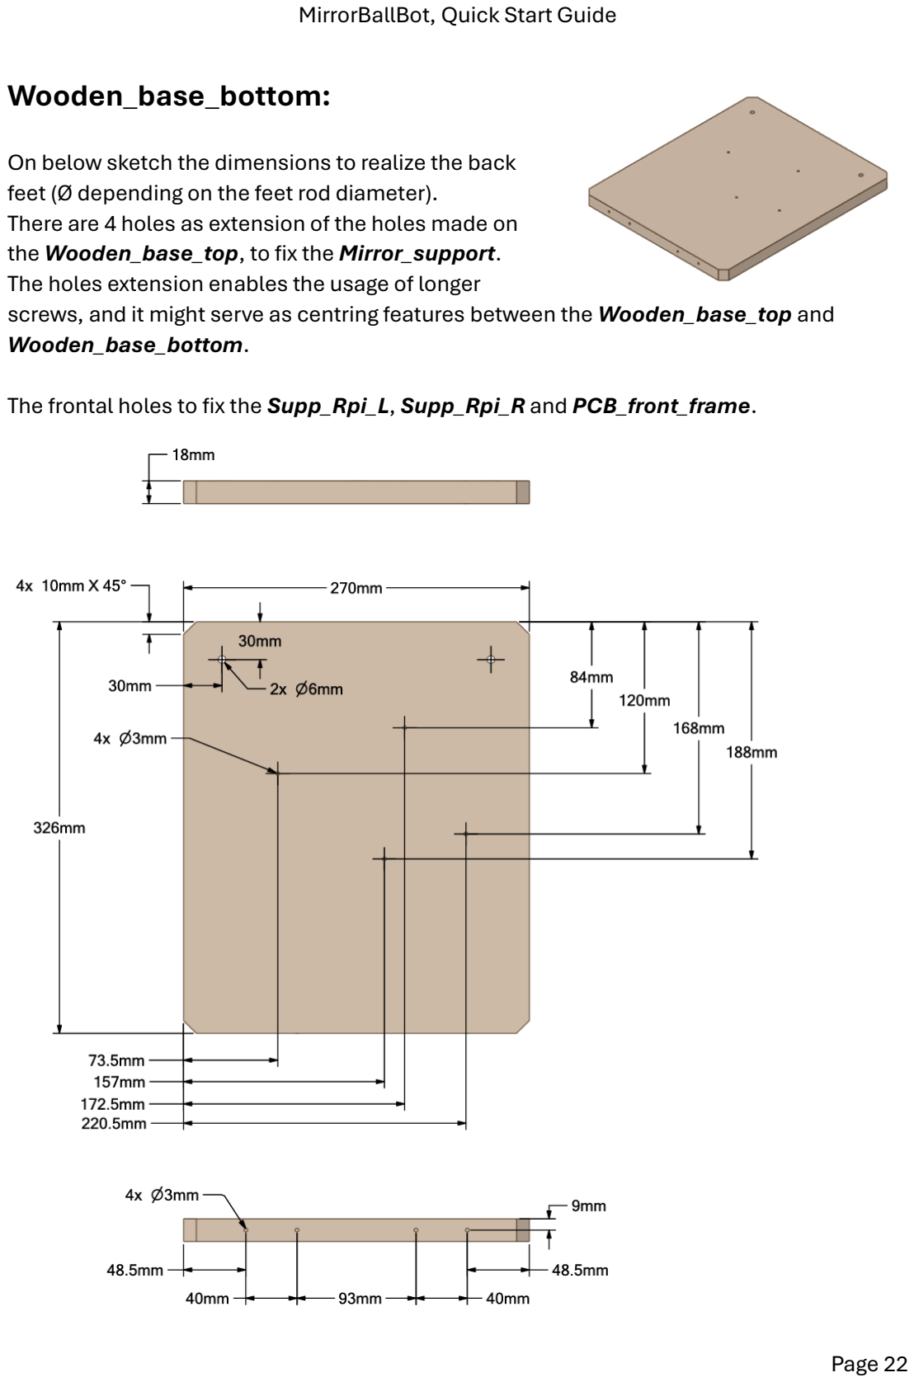
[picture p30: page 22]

On below sketch the dimensions to realize the back feet (Ø depending on the feet rod diameter).
There are 4 holes as extension of the holes made on
the Wooden_base_top, to fix the Mirror_support.
The holes extension enables the usage of longer
screws, and it might serve as centring features between the Wooden_base_top and Wooden_base_bottom.

The frontal holes to fix the Supp_Rpi_L, Supp_Rpi_R and PCB_front_frame.

After the individual wooden parts preparation:
1. Clamp both plywood layers together with good alignment
2. Drill 5 Ø3mm holes through both layers (outside the groove areas)
3. Use 3.5×30mm conical screws to join them (bottom-up)
4. Press nuts for feet into the bottom layer

Fully 3D-Printed Base Version (skip if using the wooden base version)

The base is split into three parts to fit a 210×210mm print bed.
Parts to print:
- Base_top.stl
- Base_bottom_R.stl (rear half)
- Base_bottom_F.stl (front half)

Foot supports:
- Rear_foot_support_Mx.stl (M5, M6, or M8 depending on your feet)
- Front_foot_support_Mx.stl

Important: The foot supports must be printed with the correct nut size (M5, M6, or M8) to match your adjustable feet.

## 15. Assemble the MirrorBallBot PCB

What the PCB Does
This is a passive board that connects all components together, eliminating the wiring jungle. It has ~250 solder pads—all through-hole components.

PCB Features
- Screw terminals for 20V (motors) and 5.1V (Raspberry Pi)
- Sets unique I2C addresses for each RP2040-Zero (via GPIO 7 and 8)
- Headers for stepper motors, fans, pushbuttons
- Connects RPi GPIO to RP2040-Zero boards
- Transistor for PWM fan control

Assembly Order
Step | Components | Notes
1 | Resistors, diodes, ceramic capacitors | Start from center, move outward
2 | Electrolytic capacitors (4×) | Lay on their side
3 | Female headers | For RP2040-Zero (3 sides) and TMC2209
4 | Male headers and screw terminals | Front side only
5 | 2×20 female header (back side) | Must be taller version (+5.08mm spacer)
6 | Cut protruding pins from TMC2209 | From the top side
7 | Plug in TMC2209 drivers | Ensure correct orientation
8 | Plug in RP2040-Zero boards | After programming (see Step 8)

Warning: The 2×20 GPIO header for the Raspberry Pi must be the taller version (+5.08mm) to fit properly.

On next pages the schematic (also available as PDF in the /board folder), and some pictures of the board

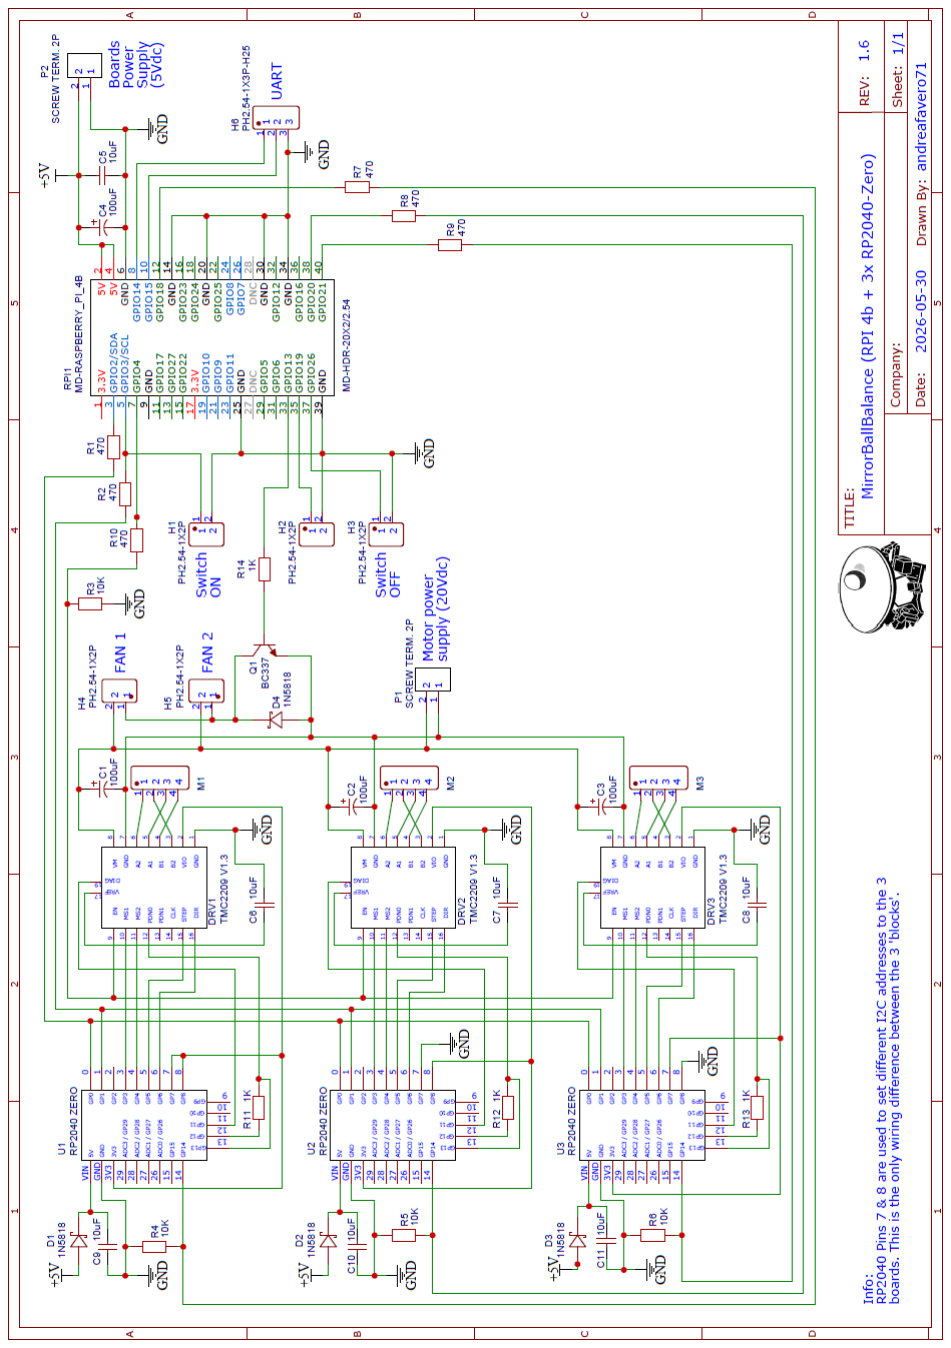
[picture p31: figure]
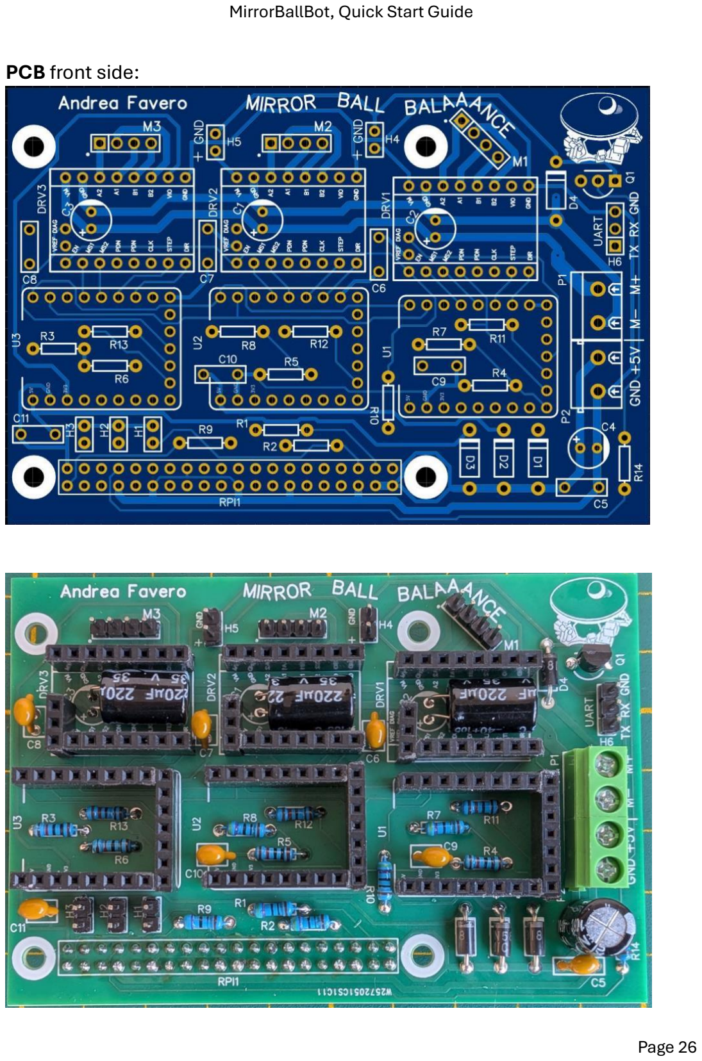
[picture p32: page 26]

PCB front side:

## 16. Prepare the Power_in box

This 3D-printed box holds:
- Power socket (matching your 20V 5A power supply)
- Two pushbuttons (ON and OFF)

Pushbutton Function
- OFF (red): Safely shuts down Raspberry Pi OS
- ON (green): Powers on the Raspberry Pi (if previously shut down)

Wiring
1. Wires should be 30~35cm long.
2. Use a 3-wire cable for the pushbuttons.
3. Connect GND to one side of both pushbuttons.
4. Connect the other side to the remaining two wires.
5. Take note of which color is ON and which is OFF.
6. Extend the power cables, if not 30~35cm long

Customizing
The Power_in.stp file is provided so you can modify it to match your power supply connector.

Tip: If using a laptop power supply like I did, you can use an adapter cable (7.4×5mm female to 5.5×2.5mm male). The socket simply presses into the 3D-printed case from the inside out.

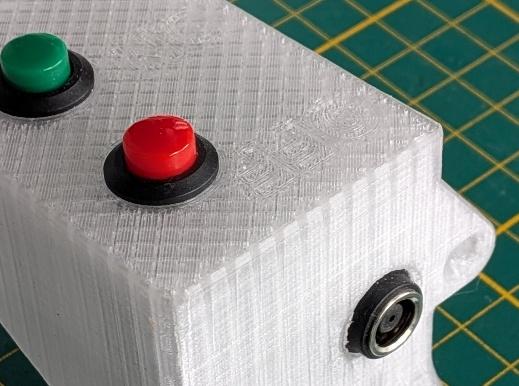
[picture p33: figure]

The Socket is simply pressed in, from the inside toward the outside of the 3D printed case.

“Computer Adapter Cable
Converter Cable 7.4x5mm
Female to 5.5x2.5mm Male
for Laptop“
https://tinyurl.com/bdz3cauv

You can edit the Power_in.stp file to redesign it to match your own power supply connector.

Red pushbutton is placed on the location with OFF engraved, the green one at the ON:

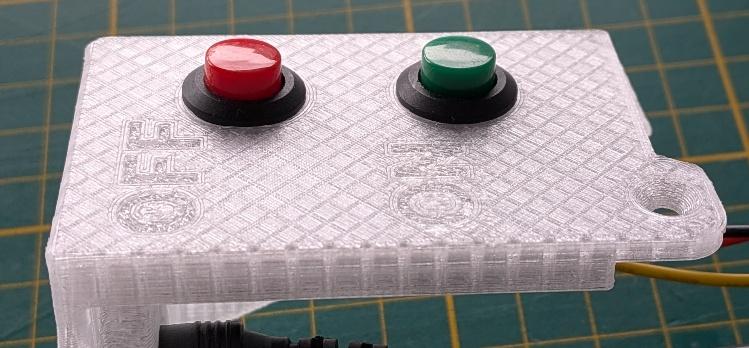
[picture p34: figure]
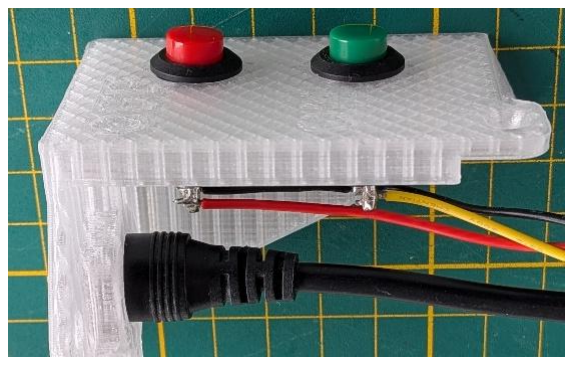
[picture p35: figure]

Use a 3 wires cable, by connecting the GND wire to one side of both pushbuttons, and the other side to the other two cables. Take note of which colour is ON and which one is OFF.

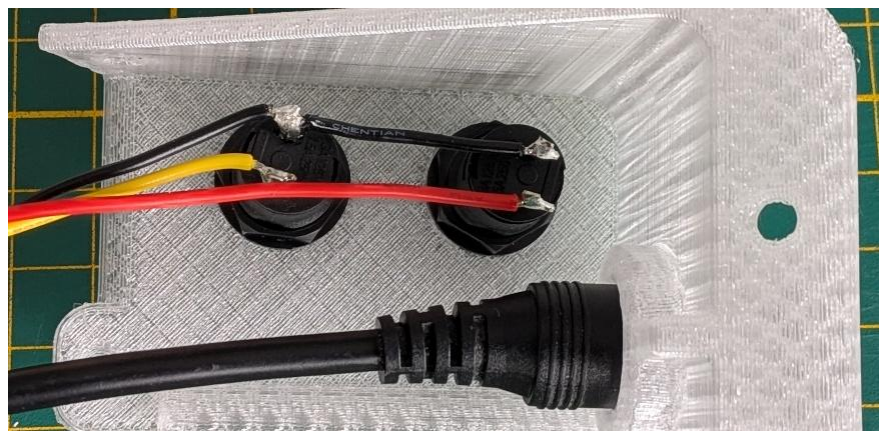
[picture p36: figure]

## 17. Calibrate the XL4015 module

WARNING: DO NOT connect the Raspberry Pi to the PCB before adjusting the XL4015!
The XL4015 module ships with its output set to maximum voltage (~20V if using a 20V supply). This will destroy your Raspberry Pi in milliseconds if connected!

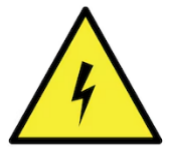
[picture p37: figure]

Calibration Procedure
1. Do not connect the XL4015 output to the PCB yet
2. Connect a multimeter to the XL4015 OUT+ and OUT-
3. Connect the XL4015 input to the Power_in power lines
4. Connect your 20V 5A power supply to the Power_in socket
5. The red LED on the XL4015 will light up
6. Using a precision screwdriver, adjust the potentiometer:
- Turn CCW several turns until the LED dims (<3V)
- Slowly turn CW to set the output to 5.1Vdc
7. Disconnect the XL4015 input from the Power_in
Now it's safe to connect the XL4015 output to the PCB.

## 18. Set up RP2040-Zero boards

Each of the three boards controls one stepper motor.
All boards use the same code: The I2C address of each board is determined by the PCB position (via GPIO 7 and 8).

Download MicroPython v1.24 for Pimoroni Tiny 2040: https://micropython.org/download/PIMORONI_TINY2040/

Process (repeat for each board)
1. Connect the RP2040-Zero via USB while holding the BOOT button
2. Drag and drop the .uf2 file to the RPI-RP2 drive
3. Copy files from the /rp2040 folder in the repository to the board:
- main.py
- rp2040_ball_balance.py
- i2c_handler.py
- i2c_responder.py
- stepper_controller.py
- shared_variables.py
- shared_memory.py
- rgb_led.py
- TMC_2209_driver.py
- TMC_2209_uart.py
4. Verify by pressing the RST button, the onboard RGB LED should flash alternating colors for ~5 seconds

Troubleshooting
If the board becomes unresponsive after booting (core1 takes over), you can:
- Press RST and immediately press STOP in Thonny, or
- Run the reset.py helper file

Updating Later
To update RP2040 code, you must remove each board from the PCB and connect via USB. No re-flashing of the firmware is needed—just copy the updated .py files.

## 19. Set up Raspberry Pi 4

WARNING DO NOT connect the Raspberry Pi to the PCB before calibrating the XL4015 to 5.1V (see related chapter).

A. Flash the OS
1. Download Raspberry Pi OS 32-bit Desktop (Trixie recommended, Bookworm also works)
2. Use Raspberry Pi Imager to flash to your microSD card
3. Set during flashing:
- Hostname (e.g., "mirrorballbot")
- Wi-Fi credentials
- Enable SSH
B. Update the OS
1. Insert the microSD into your Pi 4
2. Power the Pi with a standard 5.1V USB-C supply
3. Find the Pi's IP address (check your router or use an IP scanner)
4. Connect via SSH: ssh pi@<IP_ADDRESS> (or via Putty)
5. Run:
sudo apt update
sudo apt upgrade -y
sudo reboot
C. Clone the Repository
cd /home/pi
git clone https://github.com/AndreaFavero71/MirrorBallBot.git
D. Install Libraries
cd ~/MirrorBallBot/src
bash mbb_install.sh
This installs OpenCV, NumPy, smbus2, and other Python libraries. Takes 3-5 minutes with internet.

E. Enable VNC (optional)
Option 1: RealVNC (X11)
sudo raspi-config nonint do_wayland W1 sudo reboot
sudo systemctl enable vncserver-x11-serviced sudo systemctl start vncserver-x11-serviced

Option 2: TigerVNC (Wayland)
sudo systemctl enable wayvnc
sudo systemctl start wayvnc
F. Enable GUI Auto-Start (optional, when robot is ready)
crontab -e
Uncomment the line @reboot bash -l/home/pi/MirrorBallBot/src/mbb_start.sh

## 20. First tests

Run these tests before full assembly to catch issues early.

Before Powering On
1. Visually inspect the PCB for solder bridges
2. Check for shorts with an ohmmeter:
- +5V to GND
- +20V to GND
- +5V to +20V
3. Verify XL4015 is set to 5.1V
4. Check polarity on P1 (20V) and P2 (5.1V) terminals
5. Ensure RP2040-Zero and TMC2209 boards are fully inserted

Test Procedure

### 1. Power On

Connect the power supply. The Pi should boot and the display should show the desktop. If not, check troubleshooting in the full manual. The RP2040-Zero onboard RGB LED should flash alternating colors for ~5 seconds

### 2. Camera Test

cd ~/MirrorBallBot/src
python3 mbb_camera.py
- You should see the camera image on screen
- FPS should be above 80 (optimized >110 FPS in GUI mode)
- Press a (the graphic window should be active) for auto HSV calibration (place the ball in the centre first)
- Press q (the graphic window should be active) to quit

### 3. Fans Test

python3 mbb_fans_test.py
- Fans should run at various speeds
- Test cycles automatically and can be interrupted with CTRL+C
- Ensure correct airflow direction (left fan = intake, right fan = exhaust)

### 4. Motor Test

IMPORTANT: Motors must not have arms attached for this test!
python3 mbb_motors_test.py
- Motors should rotate slowly CCW, then faster CW
- If all motors rotate backwards, reverse the reverse parameter in mbb_settings.json
- If only 1-2 motors are reversed, rotate the connector 180° on the PCB

Set Vref on TMC2209:
1. Power down the system
2. Measure voltage between VREF pin and GND
3. Adjust the tiny potentiometer to 1.6V (for 2A motors at 80% current)
4. Formula: Vref = Imax × 80% (e.g., 2.0A × 0.8 = 1.6V)

Note: If your TMC2209 has different shunt resistors (110mΩ is typical), the Vref may vary. Check the formula in the full manual.

Test Complete?
If all tests pass, you're ready for full assembly.

## 21. Full assembly

This table summarizes the assembly steps. For detailed instructions and pictures, refer to the Full Reference Manual.

Before you start: Ensure all first tests passed.

Screw tip:
- In case screw oppose high torque, rub them on candle wax to reduce friction.
- Do not over-tighten.

Suggested steps and assembly order

(*) when specific for Fully 3D printed version, (**) when specific for the Wooden base ver.

Step | Part | Part | Action / screw (alternative screw) and head type
1 | Mirror | Mirror_support | 2x M3x10mm (M3x12mm) flat
2 | Mirror_support | (*) Base_top | 4x M4x20mm conical
| | (**) Wooden_base_top | 4x 3,5x16mm (3,5x20mm) flat
3 | Motor_support | Mirror_support | 6x M4x12mm conical
4 | Stepper motor | Motor_support | 12x M3x10mm (M3x8mm) conical
5 | Motors cables | Stepper motors | Mark the cables (A, B, C), pass them through the top base. Keep 25cm of cables protruding in front, block the rest within the grooves with tape.
6 | Power_in | Mirror_support | 3x M3x10mm (M3*12mm) conical
| | (*) Base_top | 1x M3x10mm (M3*12mm) conical
| | (**) Wooden_base_top | 1x 3,5x16mm (3,5x20mm) conical
7 (*) | Front_foot_support | Base_bottom_F | Press the (M5, M6 or M8) nut into the slot. Fix the supports to the bases: 8x M3x10mm (M3*12mm) conical
| Rear_foot_support | Base_bottom_R

Step | Part | Part | Action / screw (alternative screw) and head type
8 (*) | Base_bottom_R | Base_top | 17x M4x25mm (M4x20mm) conical
Base_bottom_F
8 (**) | Wooden_base_bottom | Wooden_base_top | 5x 3,5x30mm (3,5x25mm) conical
9 | bottom base (wood or 3D) | feet | Screw in the feet
10 | Camera_holder_low | Camera_holder_top | 1x M4x20mm (M4x35mm) conical
11 | PiCamera | Camera_holder_top | Enlarge holes at PiCamera to Ø2.5mm. Screw: 2x M2.5x6mm flat
12 | Camera_holder_low | Mirror_support | 2x M3x10mm (M3x12mm) conical
13 | Spirit_level_holder | (*) Base_top | 2x M4x 12mm conical
| | (**) Wooden_base_top | 2x 3.5x16mm (3,5x20mm) conical
14 | Spirit_level_cover | Spirit_level_holder | 1x M4x12mm conical (or flat)
15 | Arm_1 | Stepper motors | Press the arm onto the D motor’s axis. Keep the arms ~4mm from the motor. 3x M4x12mm conical
16 | Arm_2 | Spheric joints | Screw the M5 spheric joints to the Arm_2 (check if left-hand or right-handed thread)
17 | Spheric joints | Platform_support | 3x M5x30mm (M5x25mm) 6x Spacers Ø5 x Ø7~8 x 5mm screw with spacers at the spheric joints sides (see picture)
18 | Arm_2 | Arm1 | Rub a candle (wax) on the Arms flat surfaces. Screw 3x M4x30mm (M4x25mm) conical, do not tighten!
19 | Platform_support | Platform | Chamfer the six Platform’s holes; Screw 6x M4x12mm conical (M4x16mm if the Platform is 6mm thick)

Step | Part | Part | Action / notes
20 | Fan + grids Fan’s label toward the inside (electronic). | Supp_Rpi_L | Grids on both sides. 4x M3x20mm (m3x25mm) flat + washers + nuts
21 | Fan + grids Fan’s label toward the outside | Supp_Rpi_R | Grids on both sides. 4x M3x20mm (m3x25mm) flat + washers + nuts
22 | XL4015 step down module | Power_in | Connect the IN+ and IN- to the power lines (polarity matters!) Adjust the PWR_OUT to 5.1Vdc, if not done yet
23 | XL4015 step down | (*) Base_bottom_F | 2x M2,5x8mm (M2,5x10mm) flat Do not tighten
| | (**) Wooden_base_bottom | 2x M2x10mm flat, do not tighten
24 | Raspberry Pi 4 | Camera ribbon’s cable | Add heatsink to the Rpi 4. Connect the ribbon-cable to the Display Connect the Camera’s ribbon to the Rpi, fold it to stay flat and protect it with some tape against the MBB board protruding pins.
25 | Standoff screws: M2.5mm x 15mm x 6mm + M2.5 nut | Raspberry Pi 4 | If metal Standoff, use only 3 (see pictures), to limit negative impact to the Rpi Wi-Fi antenna
26 | Raspberry Pi 4 | DSI-display | Connect the Ribbon-cable to the Display’s DSI connector
27 | Supp_Rpi_L Supp_Rpi_R | DSI-display | 4x M2.5x 6mm flat
28 | MirrorBallBot PCB (inclusive of RP2040-Zero and TMC2209) | Raspberry Pi 4 | Connect the input power cables to the MBB board. Connect the MBB board to the Rpi GPIO, by centring on the screwing holes. Screw the MBB board: 4x (3x) M2.5x6mm flat
29 | Fans | MirrorBallBot PCB | Connect the fan’s (Polarity matters!)

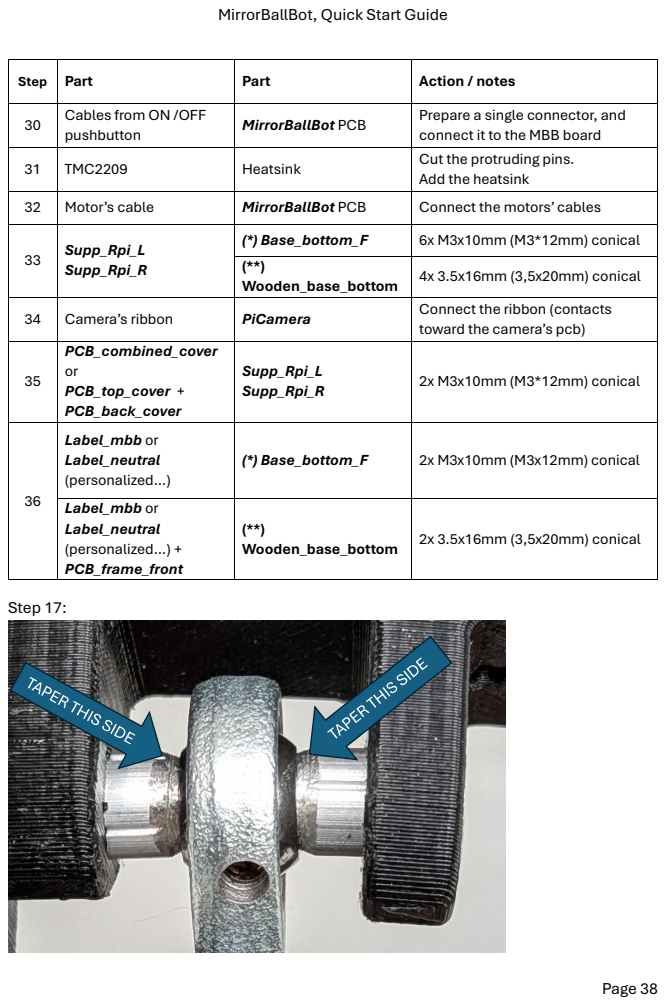
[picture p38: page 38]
Step 17:

Step | Part | Part | Action / notes
30 | Cables from ON /OFF pushbutton | MirrorBallBot PCB | Prepare a single connector, and connect it to the MBB board

31 | TMC2209 | Heatsink | Cut the protruding pins. Add the heatsink

32 | Motor’s cable | MirrorBallBot PCB | Connect the motors’ cables
33 | Supp_Rpi_L Supp_Rpi_R | (*) Base_bottom_F | 6x M3x10mm (M3*12mm) conical

(**) Wooden_base_bottom | 4x 3.5x16mm (3,5x20mm) conical

34 | Camera’s ribbon | PiCamera | Connect the ribbon (contacts toward the camera’s pcb)

35 | PCB_combined_cover or PCB_top_cover + PCB_back_cover | Supp_Rpi_L Supp_Rpi_R | 2x M3x10mm (M3*12mm) conical

36 | Label_mbb or Label_neutral (personalized…) | (*) Base_bottom_F | 2x M3x10mm (M3x12mm) conical

Label_mbb or Label_neutral (personalized…) + PCB_frame_front | (**) Wooden_base_bottom | 2x 3.5x16mm (3,5x20mm) conical

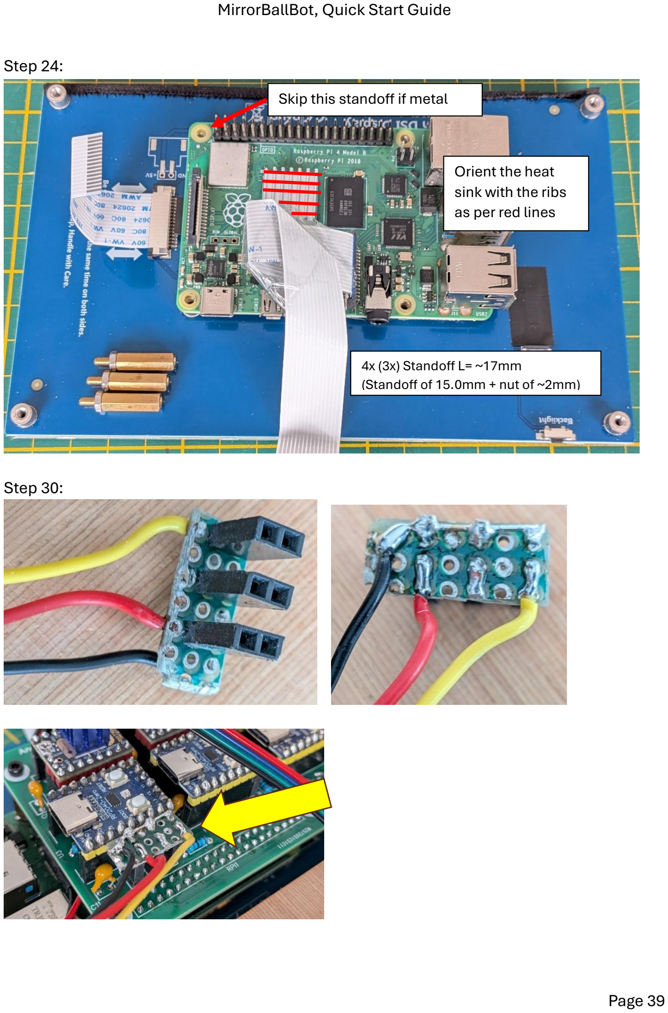
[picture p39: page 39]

Step 24:
Step 30:

Orient the heat
sink with the ribs
as per red lines

Skip this standoff if metal

4x (3x) Standoff L= ~17mm
(Standoff of 15.0mm + nut of ~2mm)

Step 32 (Connect the motors cables)
The orientation (cable’s colour order) should be the same for the 3 connectors
If the three motors rotate on the opposite direction (see “First tests” chapter), rotate the 3 connectors, or change the setting in the mbb_settings.json file.
In case only one or two motors rotate on the opposite direction, then only those connectors must be rotated.
If one or more motors don’t rotate smoothly, check the troubleshooting chapter.

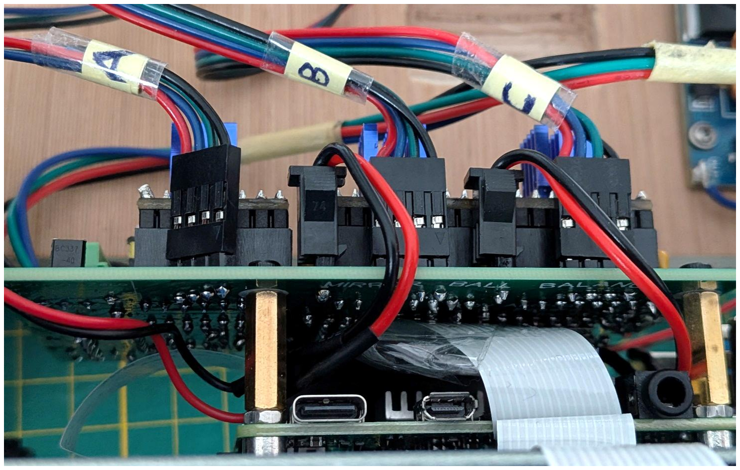
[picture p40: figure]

Step 36

The PCB_front_frame is meant for aesthetic reasons, to get the Display and the Wooden_base_bottom flashed together.
The Label_mbb (or Label_neutral personalized by you ) is also meant for aesthetic reasons.

Wooden_base version:
In this version the Label_mbb, or the Label_neutral (personalized by you) is applied over the PCB_front_cover, used to “flash” the Display bottom edge.
These two parts are kept separate to make printing easier and to achieve a better recessed text effect

Fully 3D printable version

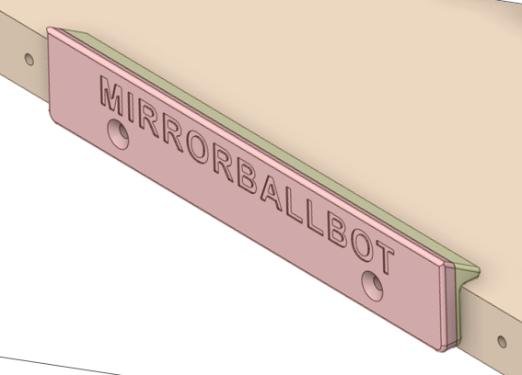
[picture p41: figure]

The Label_mbb, or the Label_neutral (personalized by you) is fix directly to the Base_bottom_F:

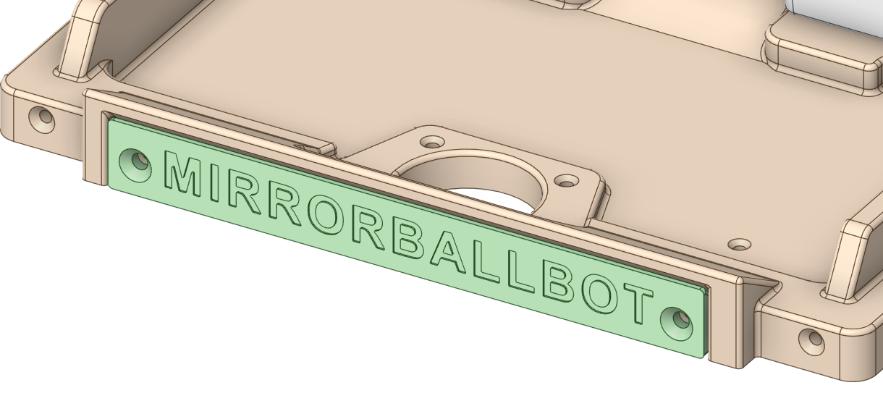
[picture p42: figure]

# Congratulations

## your MirrorBallBot is fully assembled:

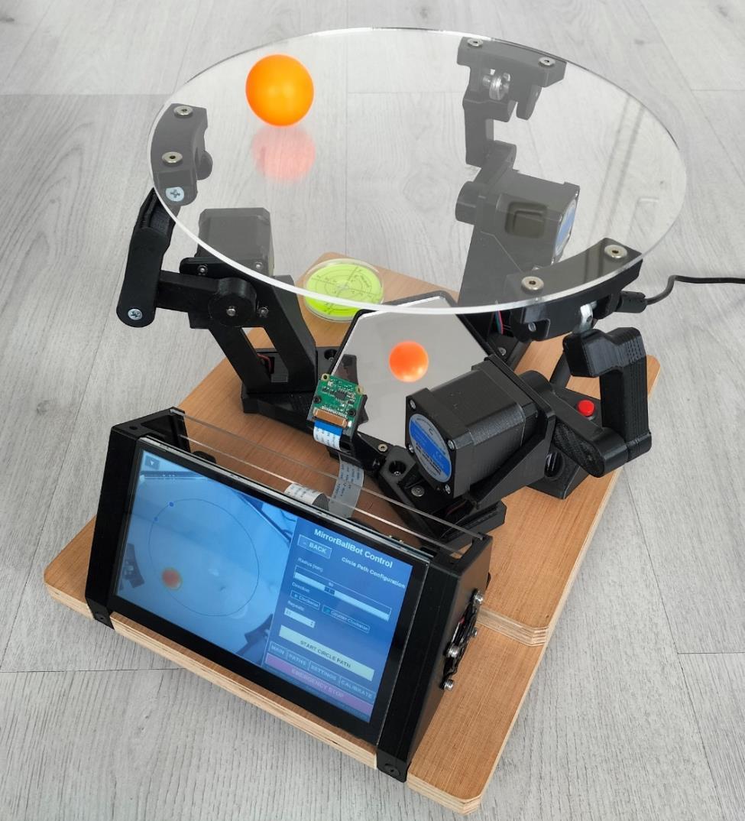
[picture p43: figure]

Fully 3D printable version (smaller base)

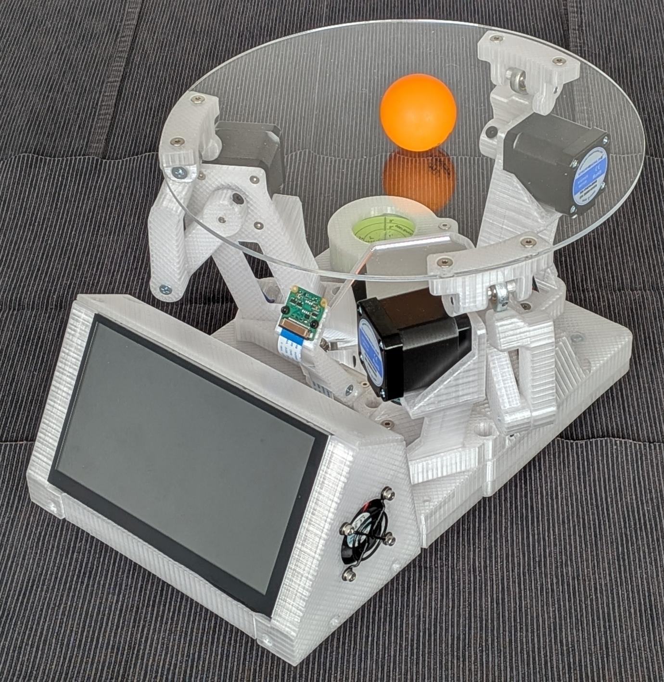
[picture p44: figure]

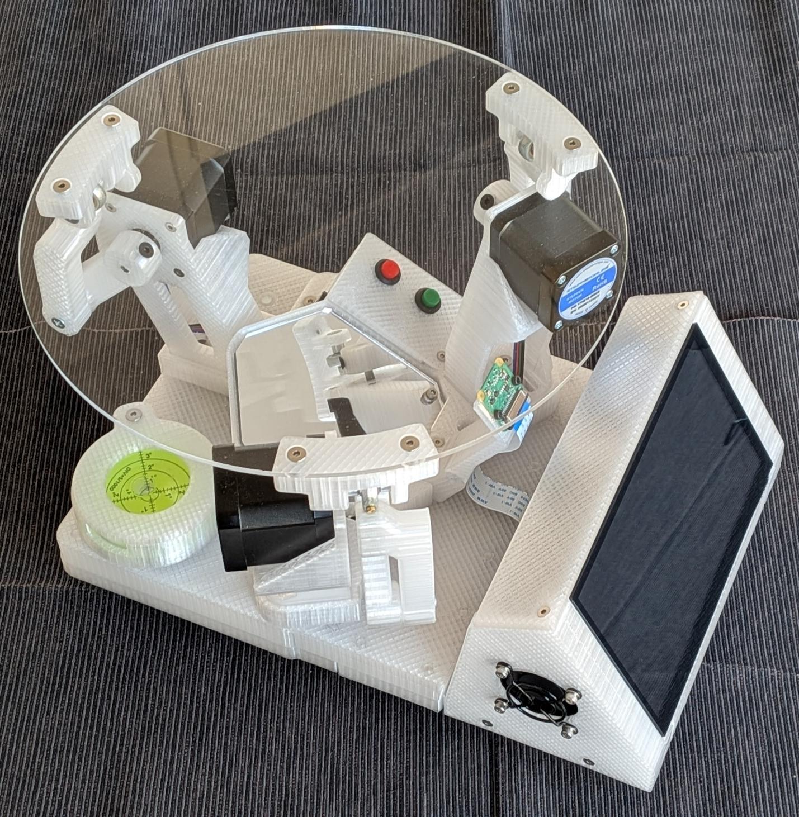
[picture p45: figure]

## 22. Calibration (brief)

This is the minimal calibration needed to get the robot working. For detailed tuning, refer to the full manual for more info.
Prerequisites:
- All first tests passed
- Robot fully assembled
- Power connected and RPi booted

Start the GUI
cd ~/MirrorBallBot/src
python3 mbb_gui.py
The GUI has three main tabs: MAIN, PATHS, and CALIBRATION.

Sensorless Homing
This tells the robot where the mechanical stops are.
1. Go to CALIBRATION → ROBOT → HOMING
2. Press "Home All Motors"
3. Each motor will rotate until it hits its stop
4. Watch the platform, all three supports should pull against the motors
5. Motor bounces back (skips steps, hits too hard), increase SG Factor (less sensitive)
6. Motor stops too early (false StallGuard trigger), decrease SG Factor (more sensitive)
Goal: All three motors stop consistently at the same position every time.

Platform Levelling
1. Place the spirit level on the platform
2. Go to CALIBRATION → ROBOT → PLATFORM
3. Adjust the three "Platform levelling (steps)" values
4. Press "Level Platform" to re-home and re-level
5. Repeat until the platform is level
Tip: Small adjustments (1-2 steps) make a noticeable difference.

Ball color calibration
1. Place the ball at the centre of the platform
2. Go to CALIBRATION → BALL
3. Ensure the "Ball Diameter (mm)" roughly matches your ball (default 30mm)
4. Press "AUTO"
5. Wait 10-20 seconds for automatic calibration
6. A green contour should appear around the ball
If AUTO fails:
- Ensure the ball is a solid color (not white, no patterns)
- Ensure the ball contrasts with the background
- Try the "MANUAL" calibration with the sliders
- Press SAVE to store the settings

PID Tuning (Basic)
1. Go to CALIBRATION → ROBOT → PID
2. Start with these values:
- Kp = 1.3
- Ki = 0.0
- Kd = 1.0
3. Go to the MAIN page and enable "Enable AUTO-Balance"
4. The ball should move toward the centre
Fine-tuning:
- If the ball oscillates (moves back and forth): increase Kd (0.1-0.2 at a time)
- If the ball drifts slowly: increase Ki (start with 0.05)
- If the ball is slow to respond: increase Kp (0.1 at a time)
Note: Ki is optional. If the platform is well levelled, Ki=0 works perfectly.

## 23. Using the robot

Starting the GUI
cd ~/MirrorBallBot/src
python3 mbb_gui.py
or double tap on the MirrorBallBot icon on the Desktop

Main Controls
Control | Function
Enable AUTO-Balance | Activates ball balancing
Home Motors | Performs sensorless homing
Balance Plat. | Moves platform to level position
Emergency Stop | Cuts power to motors (red/green button)
Target Position | Move ball to specific X/Y coordinates (mm)
Set (0,0) | Returns ball to centre

Running a Path
1. Tap the PATHS tab
2. Select a path: SQUARE, CIRCLE, INFINITY, TRIANGLE, or LINE
3. Adjust size and repeats as desired
4. Tap START to begin

Finger Following (Free Path)
1. Go to PATHS → FREE
2. Touch the screen anywhere on the camera image
3. The ball will move to your finger position
4. Drag your finger to move the ball in real-time

Record a custom path:
1. Press START REC
2. Move your finger to create a path
3. Press STOP REC
4. Press PLAY PATH to replay

Notes:
- To exit fullscreen and access the desktop, tap the ▼button at the bottom of the GUI.
- To change the Display’s backlight, press the PCB_top_cover at the recess (10 levels).

## 24. Next steps

Congratulations! You've built and calibrated your MirrorBallBot.

Where to go from here:
Resource | What You'll Find
Reference Manual | Detailed explanations, theory, design process, troubleshooting, Q&A
GitHub Repository | Latest code, STL files, PCB files, and updates Provide feedback If you enjoyed the project, consider buying me a coffee

If something isn't working:
The Quick Start Guide intentionally omits detailed troubleshooting. Refer to the Reference Manual.

If you want to understand the robot better:
The Reference Manual (Section 4) covers:
- Inspiration and design process
- The custom I2C protocol
- PID controller theory
- Software architecture

Feedback:
If you find errors or need better explanations, please let me know:
- GitHub Issues: https://github.com/AndreaFavero71/MirrorBallBot/issues
- Email: andrea.favero71@gmail.com

# Enjoy your MirrorBallBot!

## 25. Revisions

Rev | Date | Notes
0 | 09/09/2026 | First release

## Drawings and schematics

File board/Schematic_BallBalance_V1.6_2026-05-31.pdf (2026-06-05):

A | A

1

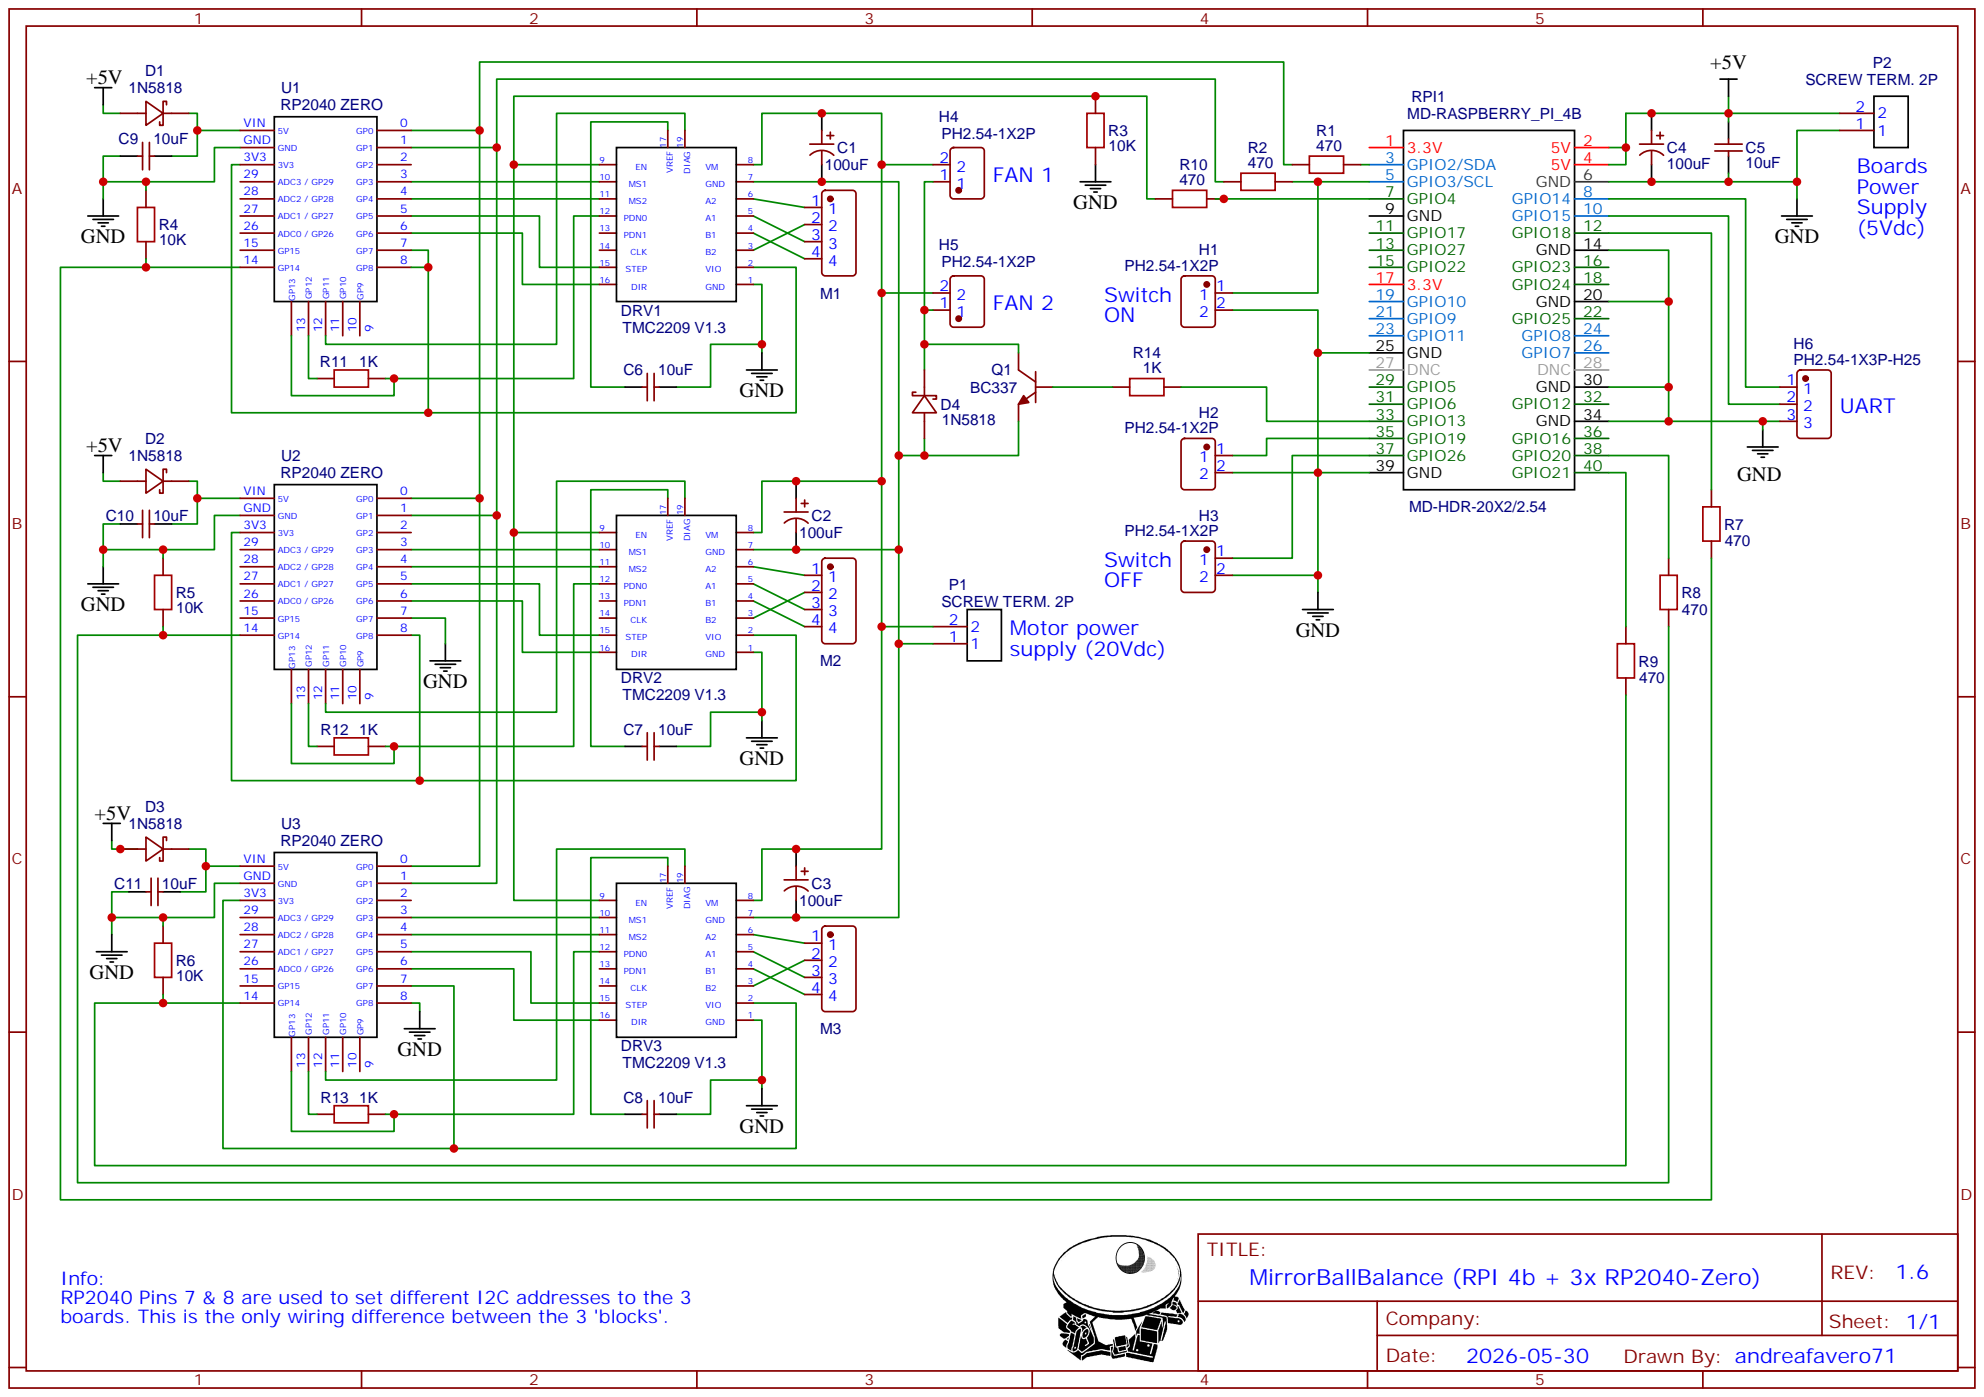
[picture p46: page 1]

Info:
RP2040 Pins 7 & 8 are used to set different I2C addresses to the 3
boards. This is the only wiring difference between the 3 'blocks'.

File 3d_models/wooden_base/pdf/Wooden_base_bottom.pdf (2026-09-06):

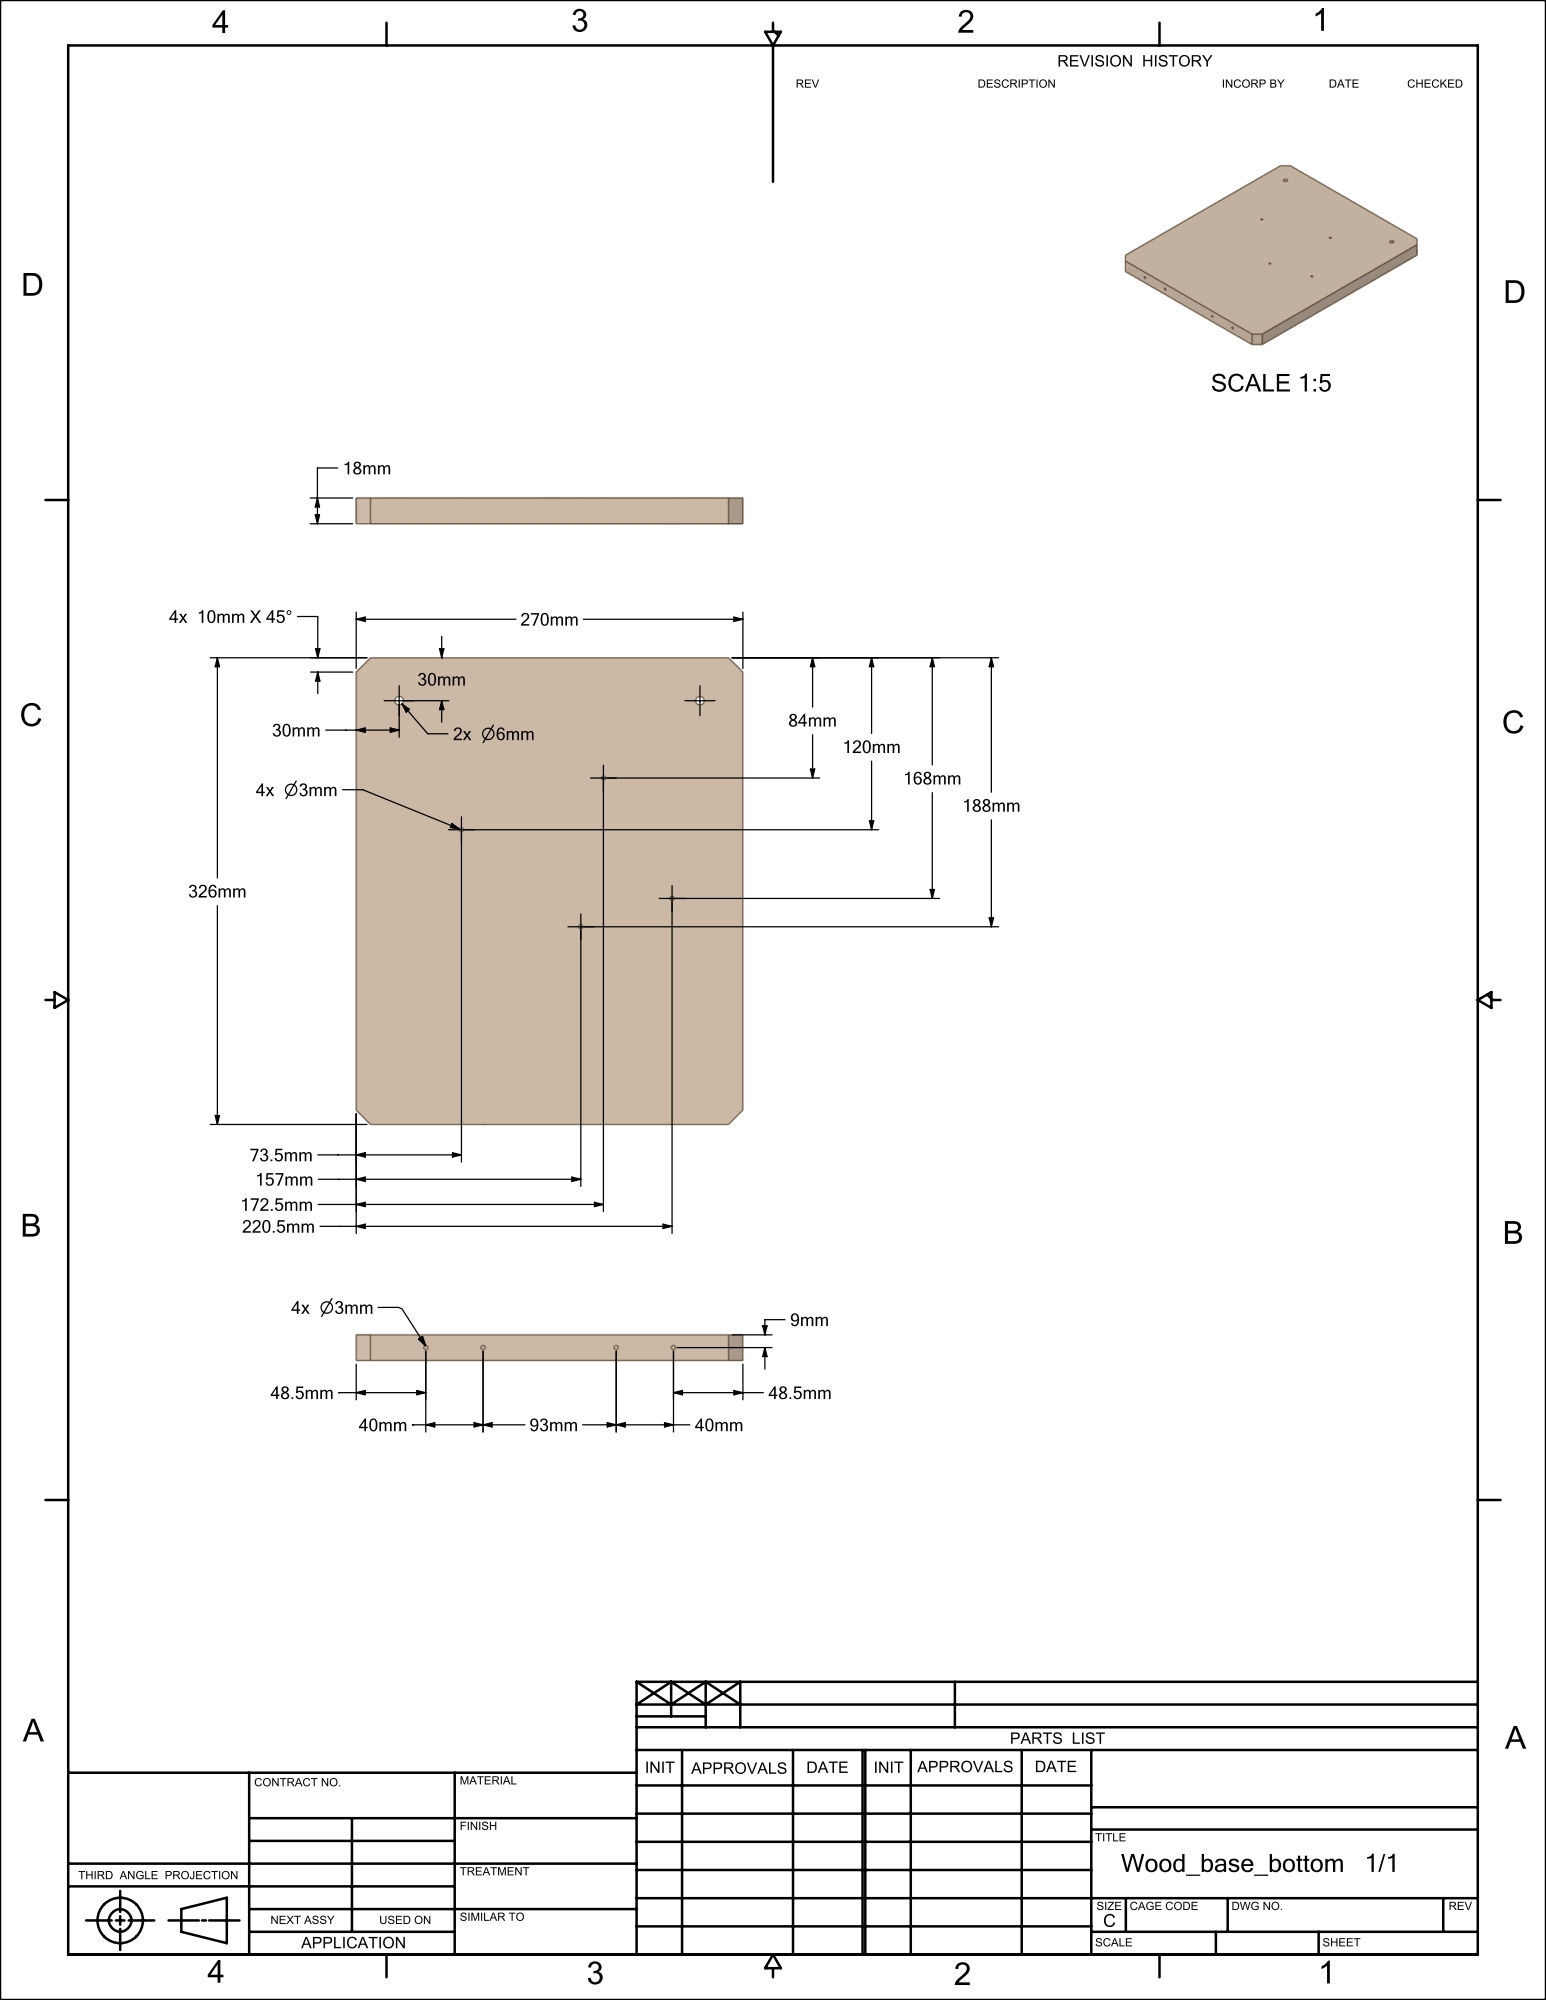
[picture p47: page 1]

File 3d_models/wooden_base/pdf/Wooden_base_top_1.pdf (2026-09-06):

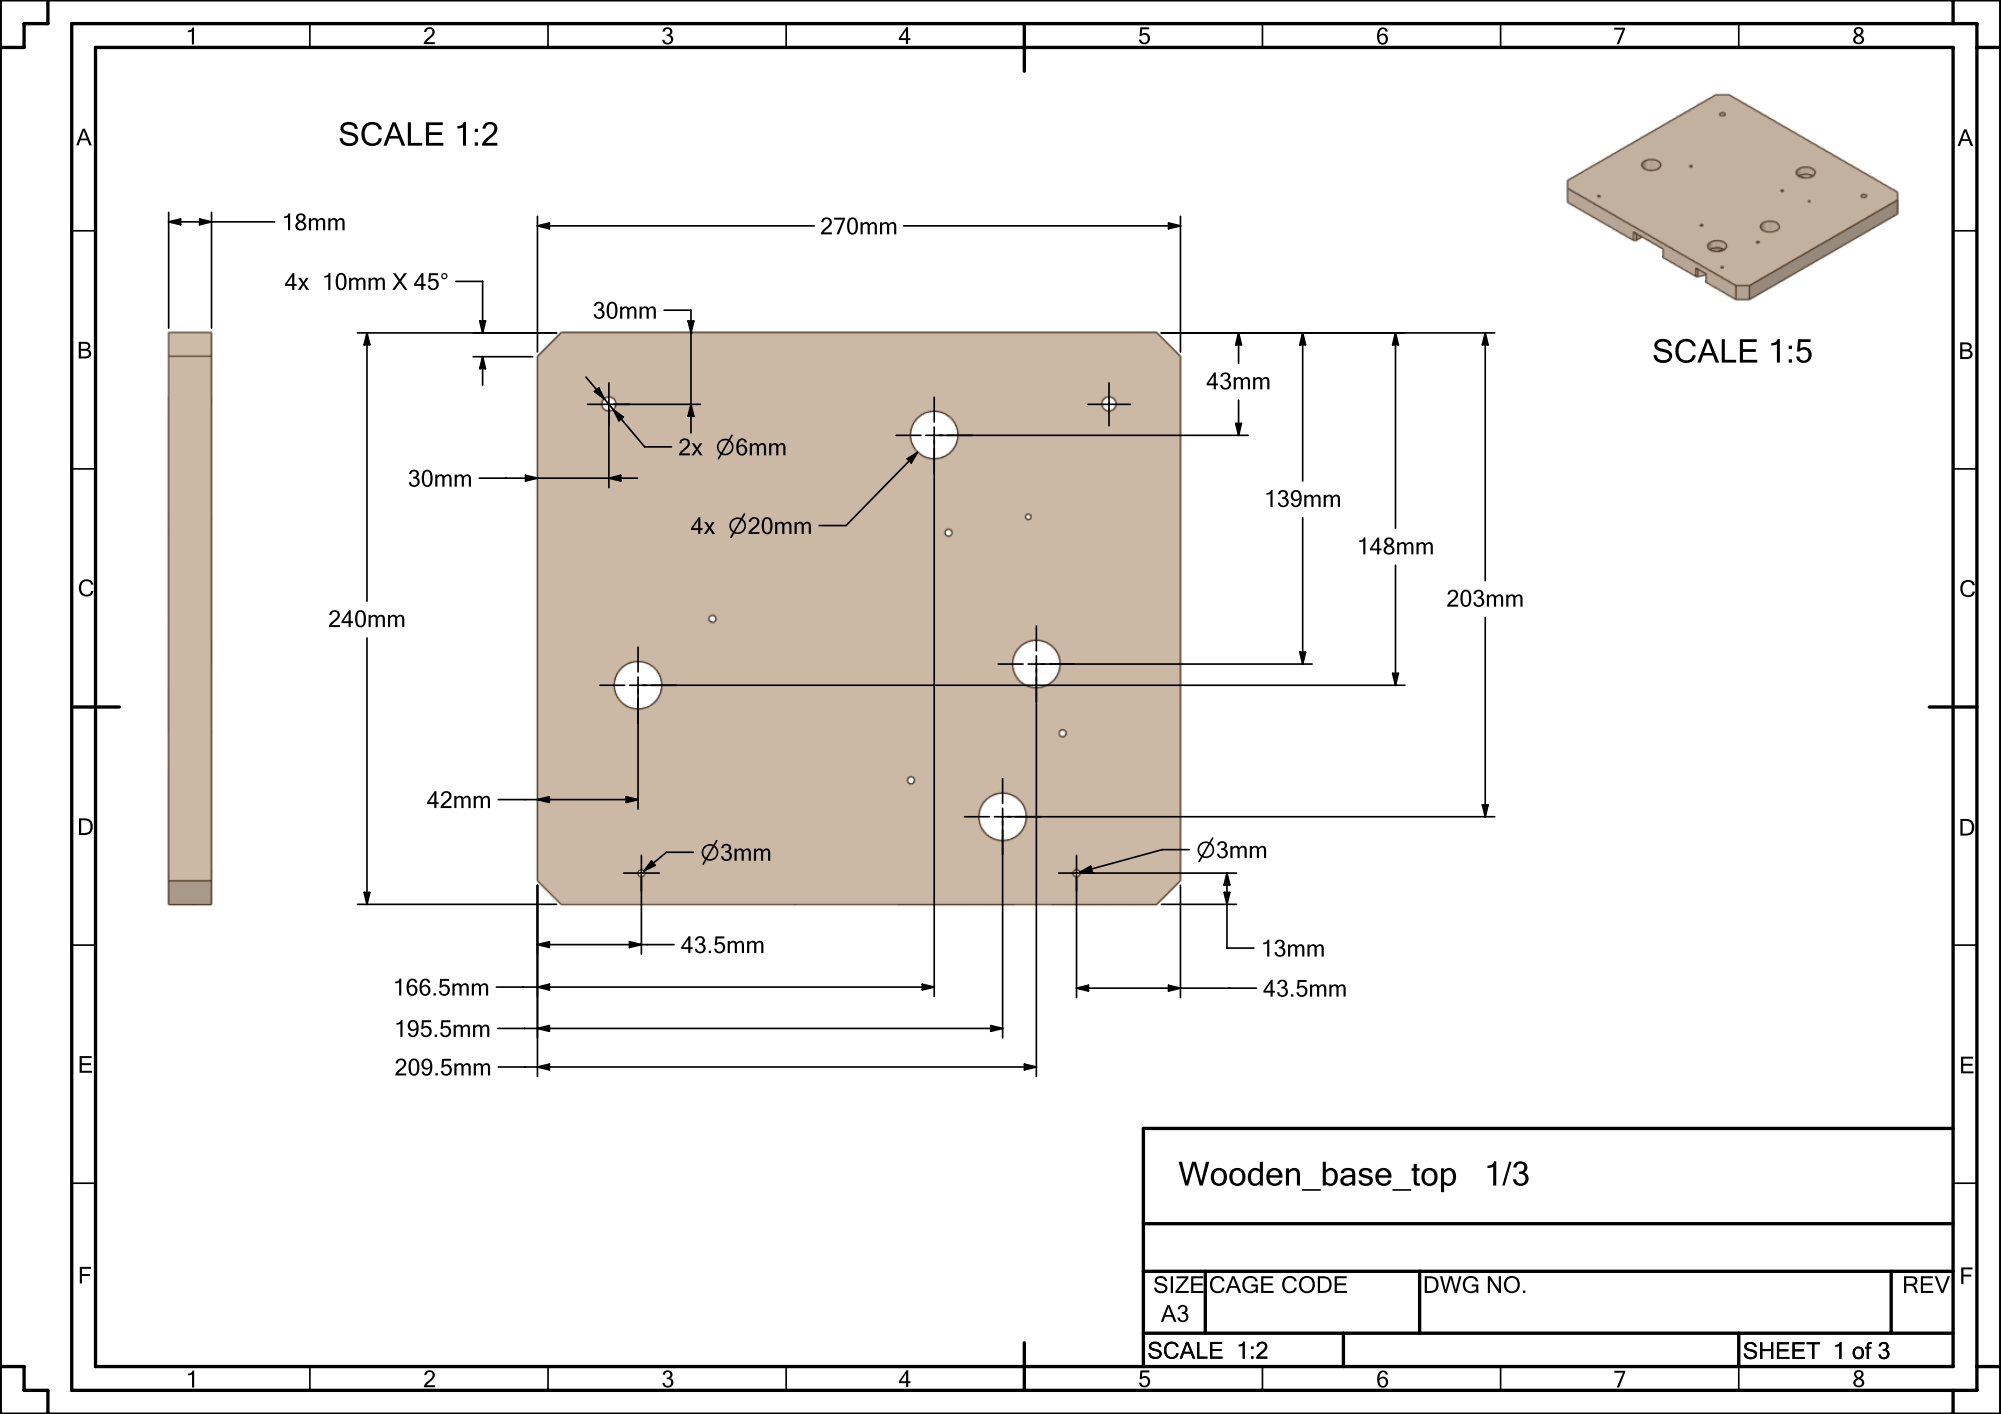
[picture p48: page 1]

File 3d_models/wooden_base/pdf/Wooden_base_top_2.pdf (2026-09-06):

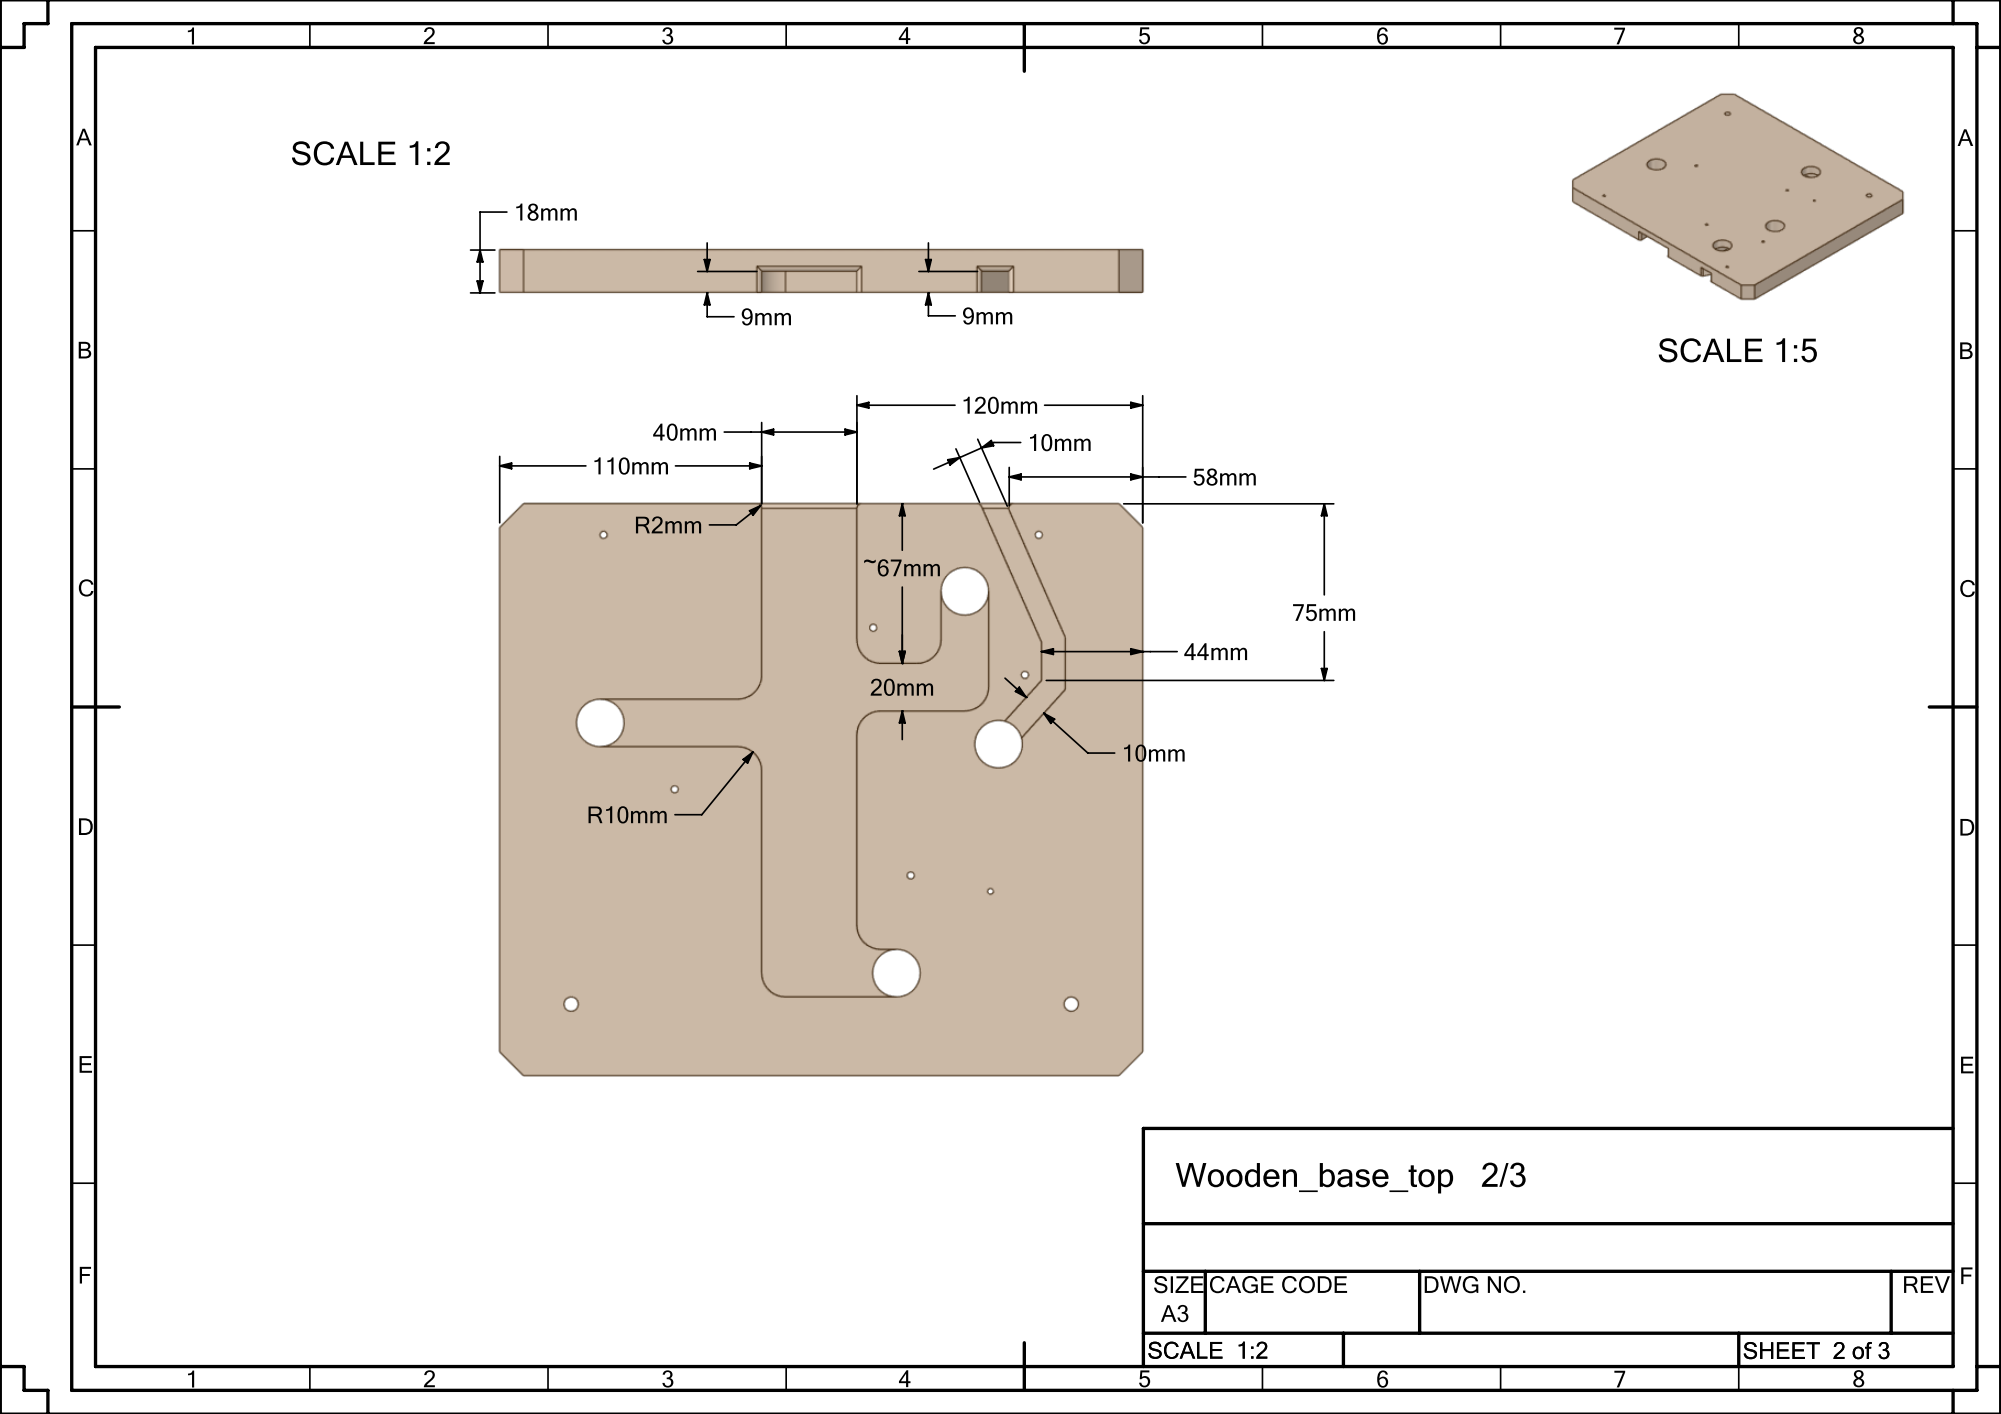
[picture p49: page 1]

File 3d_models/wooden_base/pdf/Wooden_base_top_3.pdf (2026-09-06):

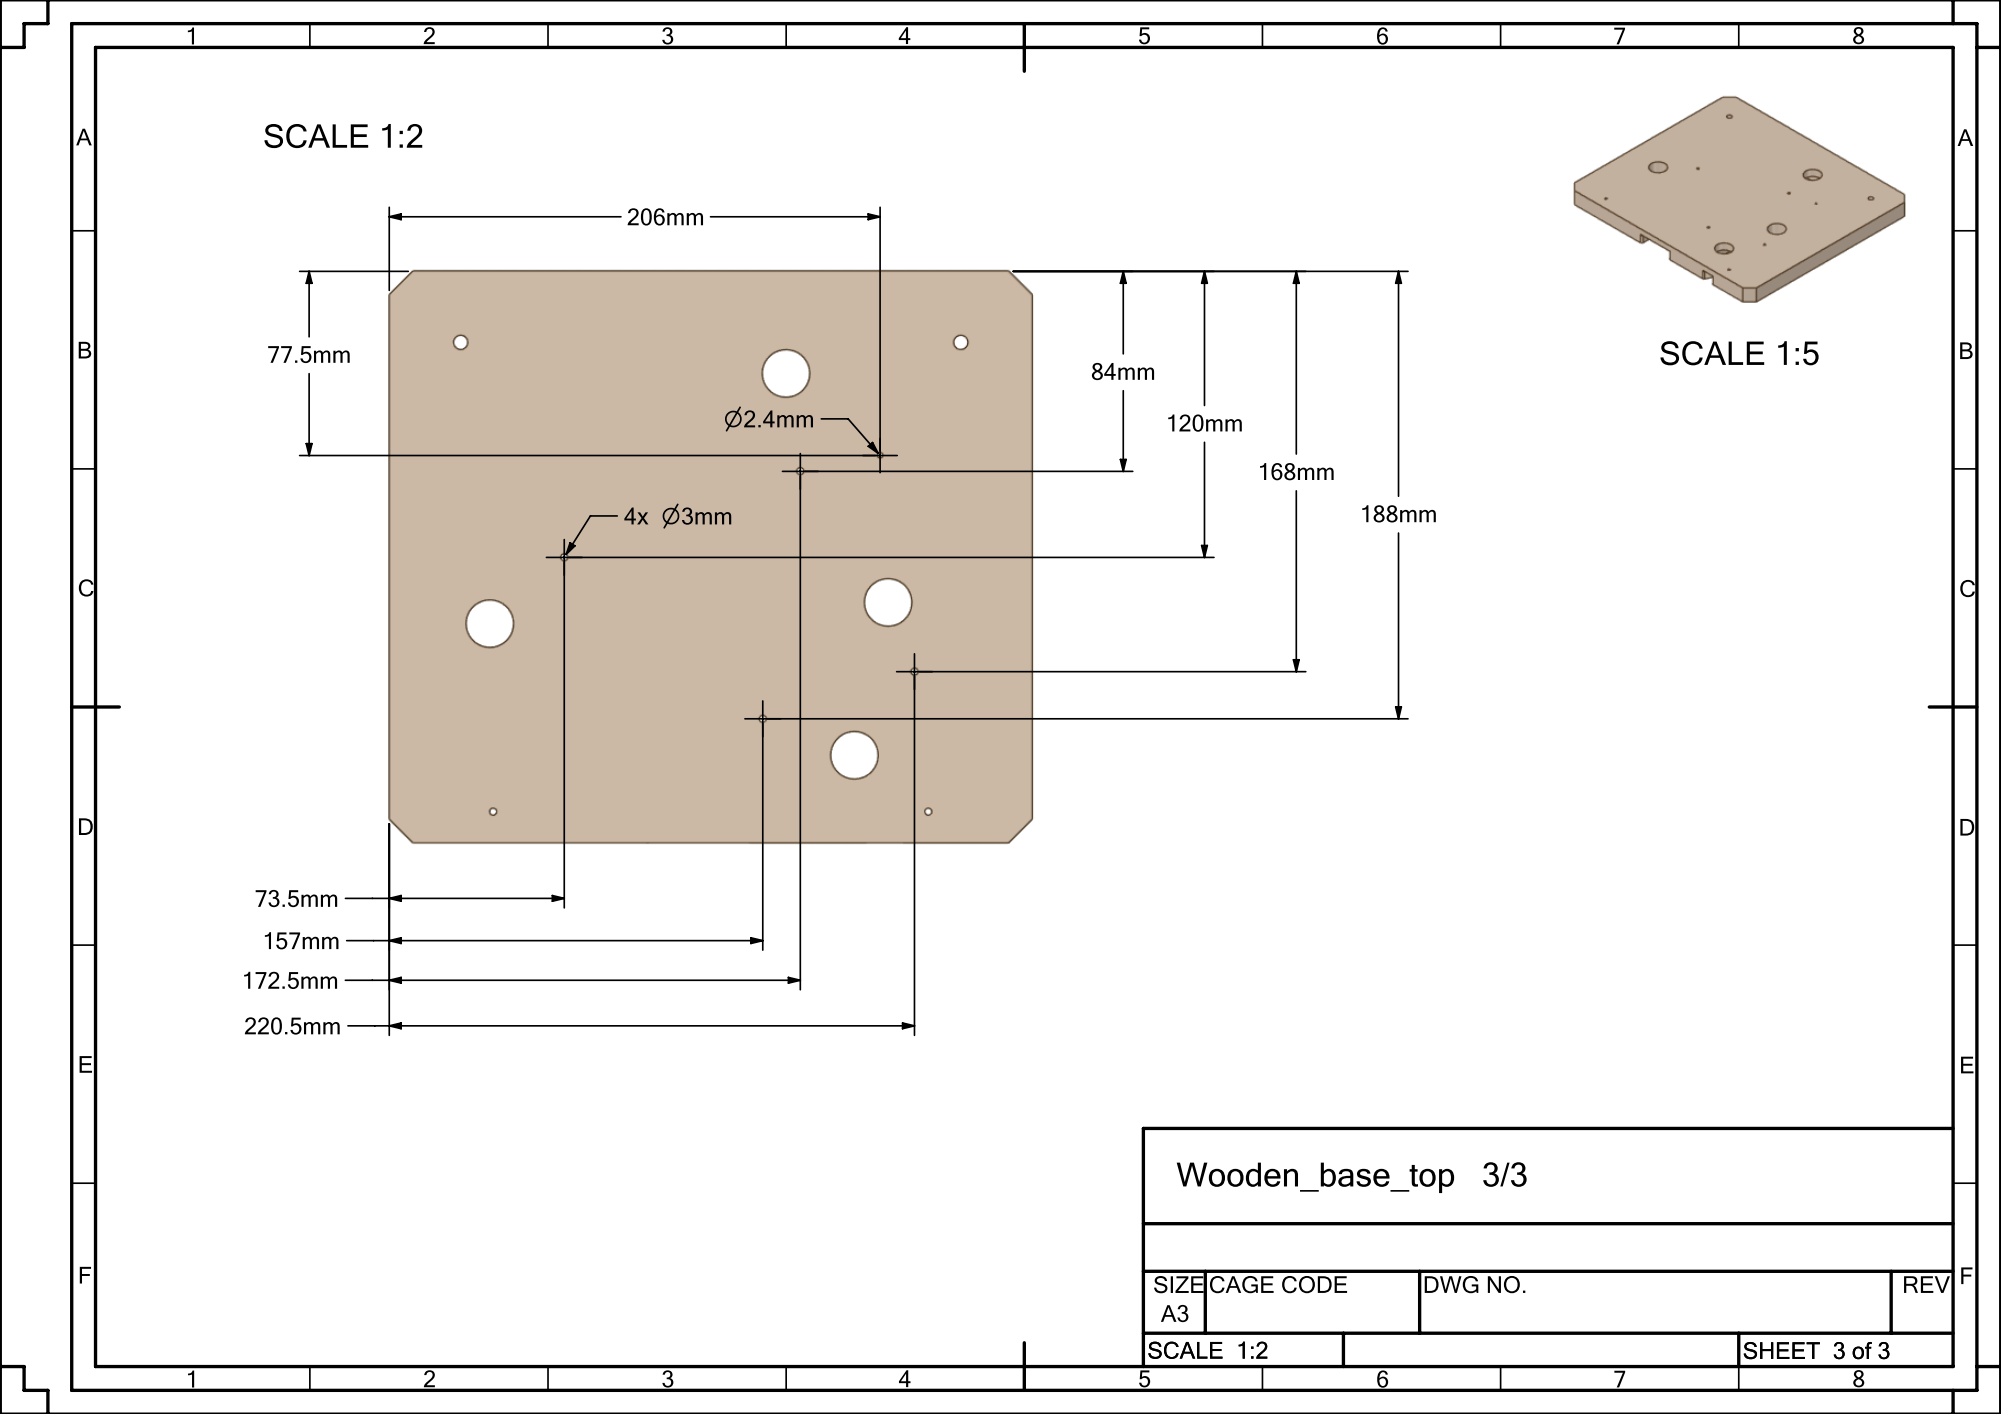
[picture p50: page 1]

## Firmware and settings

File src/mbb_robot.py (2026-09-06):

"""
Andrea Favero 20260906

MirrorBallBot (MBB), an alternative ball balance robot

More info at:
  https://github.com/AndreaFavero71/mirrorballbot
  https://www.instructables.com/MirrorBallBot-MBB-An-Alternative-Ball-Balancing-Ro/

Code handling the robot:
   - interract with the camera (get the ball position)
   - steer the steppers via I2C communication to the RP2040
   - interract with the Paths
   - control the active cooling (fans)




MIT License

Copyright (c) 2026 Andrea Favero

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
# ============================================================================
# BALL BALANCING ROBOT by ANDREA FAVERO
# ============================================================================

__version__ = "0.0.4"

from math import sqrt, radians, degrees, cos, sin, gcd
from gpiozero import OutputDevice, PWMOutputDevice
from dataclasses import dataclass
from time import time, sleep
from smbus2 import SMBus
import numpy as np
import threading
import queue
import sys


# MirrorBallBot custom modules
from mbb_display_mgr import DisplayManager
from mbb_settings_mgr import SettingsManager
from mbb_paths import PathExecutor
import mbb_camera


# ============================================================================
# MOTOR CONTROLLER
# ============================================================================

class MotorController:
    """Handles all I2C communication with stepper motors."""
    
# GPIO pins:
#     GPIO_ENABLE_PIN =  4
#     GPIO_MOT_A      = 18
#     GPIO_MOT_B      = 20
#     GPIO_MOT_C      = 21
    
    # status bit definitions (mirror RP2040 definitions)
    STATUS_BIT_ENABLED   = 0  # 1 << 0 = 1
    STATUS_BIT_MOVING    = 1  # 1 << 1 = 2
    STATUS_BIT_HOMED     = 2  # 1 << 2 = 4
    STATUS_BIT_BUSY      = 3  # 1 << 3 = 8
    STATUS_BIT_STALL     = 4  # 1 << 4 = 16
    STATUS_BIT_ERROR     = 5  # 1 << 5 = 32
    STATUS_BIT_HOMING    = 6  # 1 << 6 = 64
    STATUS_BIT_RETRACT   = 7  # 1 << 7 = 128
    
    # predefined masks for common conditions
    STATUS_MASK_HOMING = (1 << STATUS_BIT_HOMING) | (1 << STATUS_BIT_RETRACT)
    STATUS_MASK_BUSY   = (1 << STATUS_BIT_BUSY)   | (1 << STATUS_BIT_MOVING)
    STATUS_MASK_READY  = (1 << STATUS_BIT_ENABLED)  # must also check not busy
    
    # special I2C response values
    I2C_RESPONSE_NO_DATA        = 254
    I2C_RESPONSE_CHECKSUM_ERROR = 255
    
    
    
    def __init__(self, verbose=False, settings_mgr=None):
        """
        Handles all I2C communication with stepper motors.
        
        Args:
            settings_mgr: SettingsManager instance
            verbose: If True, print debug information
        """
        
        # verbose mode
        self.verbose = verbose
        
        self.settings_mgr = settings_mgr
        
        # load motor settings if available
        if self.settings_mgr:
            settings = self.settings_mgr.get()
            self.GPIO_ENABLE_PIN = settings.gpio.motors_drv_enable
            self.GPIO_MOT_A = settings.gpio.motor_a
            self.GPIO_MOT_B = settings.gpio.motor_b
            self.GPIO_MOT_C = settings.gpio.motor_c
            self.REVERSE    = settings.motors.reverse
            self.MAX_SPEED  = settings.motors.max_speed
            self.MIN_SPEED  = settings.motors.min_speed
            self.BASE_SPEED = settings.motors.base_speed
        else:
            # fallback defaults
            self.GPIO_ENABLE_PIN =  4
            self.GPIO_MOT_A = 18
            self.GPIO_MOT_B = 20
            self.GPIO_MOT_C = 21
            self.REVERSE    = False
            self.MAX_SPEED  = 65480
            self.MIN_SPEED  = 5000
            self.BASE_SPEED = 55000
        
        # I2C setup
        self.bus = SMBus(1)
        self.motors = {'A': 0x41, 'B': 0x42, 'C': 0x43}
        
        # communication constants
        self.STX = 0x02
        self.ETX = 0x03
        
        # hard reset the RP2040 boards
        self.reset_pico()
        
        # Pin object to enable/disable the stepper drivers
        self.motors_enable_pin = OutputDevice(self.GPIO_ENABLE_PIN)
        
        # disable the motors (no current to their coils)
        # motors will be enabled when positioning th platform the first time
        self.disable_motors()
        
        # variable to track the motor enable status
        self.motors_enabled = False
        
        # dict of Pins objects to syncronize the motors
        self.motors_sync_pins = {
            'A': OutputDevice(self.GPIO_MOT_A),
            'B': OutputDevice(self.GPIO_MOT_B),
            'C': OutputDevice(self.GPIO_MOT_C)
            }
        
        # set the motors syncronization pins to low
        # when data at the PIO buffer, the stepper start at rising edge of the sync_pin
        for pin in self.motors_sync_pins.values():
            pin.off()
        
        # stepper direction as per default or reverse it
        self.reverse_motors(self.REVERSE)
        
        # PIO parameters
        self.PIO_FIX = 8
        self.PIO_VAR = 4
        self.PIO_FREQUENCY = 5_000_000
        self.PIO_MULTIPLIER = 8              # factor increasing the received speed via I2C to the one used by the PIO
        
        # speed control
        self.MAX_NORMALIZED_SPEED = 100_000
        self.MIN_DELAY = 100
        self.MAX_DELAY = 32767
        self.STOP_WORD = 32768
        
        self.f_min = self.PIO_FREQUENCY // (self.PIO_MULTIPLIER * self.MAX_DELAY * self.PIO_VAR + self.PIO_FIX)
        self.f_max = self.PIO_FREQUENCY // (self.PIO_MULTIPLIER * self.MIN_DELAY * self.PIO_VAR + self.PIO_FIX)
        self.f_range = self.f_max - self.f_min
        
        if self.verbose:
            print("\nMotorController initialized")
    
    
    
    
    
    def normalized_speed_to_delay(self, norm_speed: int) -> tuple[int, int]:
        """Convert normalized speed to PIO delay value."""
        norm_speed = max(-self.MAX_NORMALIZED_SPEED, min(self.MAX_NORMALIZED_SPEED, norm_speed))
        
        if abs(norm_speed) < 1:
            return 0, 0
        
        f_target = self.f_min + self.f_range * abs(norm_speed) // self.MAX_NORMALIZED_SPEED
        
        if f_target == 0:
            return 0, 0
            
        pio_delay = (self.PIO_FREQUENCY // f_target - self.PIO_FIX) // (self.PIO_MULTIPLIER * self.PIO_VAR)
        pio_delay = max(self.MIN_DELAY, min(self.MAX_DELAY, pio_delay))
        
        # determine stepper direction, based on speed >0 and self.REVERSE
        needs_inversion = (norm_speed > 0) == self.REVERSE
        
        # define the speed_word to send to the RP2040
        speed_word = pio_delay if needs_inversion else 65535 - pio_delay
        
        return pio_delay, speed_word
    
    
    
    def calculate_movement_time(self, pio_delay: int, steps: int) -> int:
        """Calculate movement time in milliseconds."""
        if pio_delay == 0:
            return 10         # 10 ms
        
        if steps <= 0:
            return 10         # 10 ms
        
        elif steps < 4:
            step_time_us = (self.PIO_MULTIPLIER * pio_delay * self.PIO_VAR + self.PIO_FIX) * 1000000 // self.PIO_FREQUENCY
            return (steps * step_time_us) // 1000
        
        # long sequence of is cases, turned out to be faster than several other approaches
        elif steps >= 32:
            steps_ramp = 8
        elif steps >= 28:
            steps_ramp = 7
        elif steps >= 24:
            steps_ramp = 6
        elif steps >= 20:
            steps_ramp = 5
        elif steps >= 16:
            steps_ramp = 4
        elif steps >= 12:
            steps_ramp = 3
        elif steps >= 8:
            steps_ramp = 2
        elif steps >= 4:
            steps_ramp = 1

        speed_reduction = 1.5
        delay_ramp = min(int(speed_reduction * pio_delay), 262143)
        step_time_ramp_us = (self.PIO_MULTIPLIER * delay_ramp * self.PIO_VAR + self.PIO_FIX) * 1000000 // self.PIO_FREQUENCY
        step_time_us = (self.PIO_MULTIPLIER * pio_delay * self.PIO_VAR + self.PIO_FIX) * 1000000 // self.PIO_FREQUENCY
        movement_time_us = (2 * steps_ramp * step_time_ramp_us)
        movement_time_us += ((steps - 2 * steps_ramp) * (step_time_us))
        return movement_time_us//1000

    
    def i2c_test(self):
        """Send a I2C query command to all motors (RP2040)."""
        responses = 0
        for motor in self.motors:
            # send motor status query commands (special command 7)
            ret = self.send_command(motor, 7, 1)
            if ret is not None:
                responses += 1
                sleep(0.01)
                if self.verbose:
                    print(f"Motor {motor} status is: {ret}")
        if responses == 3:
            return True
        else:
            return False
    
    
    def calculate_checksum(self, dataframe):
        return sum(dataframe) & 0xFF
    
    
    def escape_data(self, dataframe):
        escaped_data = []
        for byte in dataframe:
            if byte in [self.STX, self.ETX, 0x5C]:
                escaped_data.append(0x5C)
            escaped_data.append(byte)
        return escaped_data
    
    
    def send_command(self, motor: str, speed_word: int, steps: int):
        """Send command to a single motor using I2C speed_word."""
        
        # special handling for status request (command 7)
        if speed_word == 7:
            # just read status, no need to send data
            # the I2C handler will return status on read
            return True
        
        data_frame = [self.STX]
        for value in [speed_word, steps]:
            field_bytes = value.to_bytes(2, byteorder='big')
            data_frame += list(field_bytes)
        
        checksum = self.calculate_checksum(data_frame)
        data_frame.append(checksum)
        escaped_data = self.escape_data(data_frame)[1:] + [self.ETX]
        
        address = self.motors[motor]
        try:
            self.bus.write_i2c_block_data(address, 0, escaped_data)
            return True
        except Exception as e:
            print(f"I2C error motor {motor}: {e}")
            return False
    
    
    def read_response(self, motor: str):
        """Read response from motor."""
        address = self.motors[motor]
        try:
            response = self.bus.read_byte(address)
            return response
        except Exception as e:
            print(f"I2C read error motor {motor}: {e}")
            return self.I2C_RESPONSE_CHECKSUM_ERROR  # return checksum error on exception
    
    
    def sync_motors(self, motors: str):
        """
        Sync multiple motors.
        The PIO stepper generator waits for a GPIO pin to be high to start.
        This is used to activate the 3 stepper in parallel, after sending them the
        instruction in sequence via the I2C.
        Not tested if really needed...but it sounds a robust approach.
        """
    
        # get the pin objects for the requested motors
        active_pins = [self.motors_sync_pins[m] for m in motors if m in self.motors_sync_pins]
        
        # set the pin on
        for pin in active_pins:
            pin.on()
        
        # short wait time
        sleep(0.01)
        
        # set the pin off again
        for pin in active_pins:
            pin.off()
    
    
    
    def enable_motors(self):    
        """Enable all motors (EN pin of the stepper driver)."""
        self.motors_enable_pin.off()
        
        # send enable commands (special command 3)
        for motor in self.motors:
            self.send_command(motor, 3, 1)
            sleep(0.1)
        self.motors_enabled = True
    
    
    
    def disable_motors(self):
        """Disable all motors (EN pin of the stepper driver)."""
        self.motors_enable_pin.on()
        
        # send enable commands (special command 2)
        for motor in self.motors:
            self.send_command(motor, 2, 1)
            sleep(0.1)
        self.motors_enabled = False
    
    
    
    def reverse_motors(self, reverse):
        """
        Maintain or reverse the direction of the stepper motors
        0 (or False) maintains the default direction (my MBB)
        1 (or True) reverses the default direction (compared to my MBB)
        """
        
        # send reverse command (special command 8)
        for motor in self.motors:
            self.send_command(motor, 8, int(reverse))
            sleep(0.1)

    
    
    def reset_pico(self):
        """
        Hard reset of the RP2040 or RP2350, via I2C command.
        Necessary to wait at least 6 seconds for the RP2040 to reboot,
        prior to send other commands
        """
        
        print("\nHard reset of the RP2040 (wait 6 seconds to reboot)") 
        # send reset command to the board (special command 9)
        for motor in self.motors:
            self.send_command(motor, 9, 1)
            if self.verbose:
                print(f"Reset of the RP2040 board for motor {motor}")
        sleep(6)
        print()
    
    
    
    def decode_status(self, status_byte):
        """Decode status byte into human-readable string."""
        if status_byte == self.I2C_RESPONSE_NO_DATA:
            return "NO_DATA"
        if status_byte == self.I2C_RESPONSE_CHECKSUM_ERROR:
            return "CHECKSUM_ERROR"
        
        states = []
        if status_byte & (1 << self.STATUS_BIT_ENABLED): states.append("ENABLED")
        if status_byte & (1 << self.STATUS_BIT_MOVING):  states.append("MOVING")
        if status_byte & (1 << self.STATUS_BIT_HOMED):   states.append("HOMED")
        if status_byte & (1 << self.STATUS_BIT_BUSY):    states.append("BUSY")
        if status_byte & (1 << self.STATUS_BIT_STALL):   states.append("STALL")
        if status_byte & (1 << self.STATUS_BIT_ERROR):   states.append("ERROR")
        if status_byte & (1 << self.STATUS_BIT_HOMING):  states.append("HOMING")
        if status_byte & (1 << self.STATUS_BIT_RETRACT): states.append("RETRACT")
        
        return " | ".join(states) if states else "IDLE"
    
    
    
    
    def read_status(self, motor):
        """Read motor status."""
        try:
            status = self.bus.read_byte(self.motors[motor])
            return status
        except Exception as e:
            print(f"Read error: {e}")
            return self.I2C_RESPONSE_CHECKSUM_ERROR

    
    
    def request_status_update(self, motor):
        """Request a status update from RP2040 (command 7)."""
        self.send_command(motor, 7, 1)
        sleep(0.01)
        return self.read_status(motor)
    
    
    
    def wait_for_status(self, motor, expected_bits=None, clear_bits=None, timeout_s=2, interval_s=0.05):
        """
        Wait for motor status to meet conditions.
        
        Args:
            motor: Motor identifier
            expected_bits: Bits that must be set (bitmask)
            clear_bits: Bits that must be cleared (bitmask)
            timeout_s: Maximum time to wait in seconds
            interval_s: Time between status checks
        
        Returns:
            tuple: (success, final_status)
        """
        start_time = time()
        
        while (time() - start_time) < timeout_s:
            # request fresh status
            status = self.request_status_update(motor)
            
            # skip invalid responses
            if status in (self.I2C_RESPONSE_NO_DATA, self.I2C_RESPONSE_CHECKSUM_ERROR):
                sleep(interval_s)
                continue
            
            # check conditions
            conditions_met = True
            if expected_bits is not None:
                if (status & expected_bits) != expected_bits:
                    conditions_met = False
            if clear_bits is not None:
                if (status & clear_bits) != 0:
                    conditions_met = False
            
            if conditions_met:
                return True, status
            
            sleep(interval_s)
        
        return False, self.request_status_update(motor)
    
    
    
    def are_motors_busy(self, timeout_s=5.0):
        """
        Check if any motor is busy (moving, homing, etc.)
        Returns (is_busy, status_message, busy_motors_list)
        """
        start_time = time()
        busy_motors = []
        
        while (time() - start_time) < timeout_s:
            busy_motors = []
            
            for motor in self.motors.keys():  # A, B, C
                # request fresh status
                status = self.request_status_update(motor)
                
                # skip invalid responses
                if status in (self.I2C_RESPONSE_NO_DATA, self.I2C_RESPONSE_CHECKSUM_ERROR):
                    busy_motors.append(f"{motor}(ERR)")
                    continue
                
                # check busy bits: BUSY, MOVING, HOMING, RETRACT
                busy_bits = (1 << self.STATUS_BIT_BUSY) | \
                            (1 << self.STATUS_BIT_MOVING) | \
                            (1 << self.STATUS_BIT_HOMING) | \
                            (1 << self.STATUS_BIT_RETRACT)
                
                if status & busy_bits:
                    busy_motors.append(motor)
            
            if not busy_motors:
                return False, "READY", []
            
            # still busy, wait and retry
            sleep(0.1)
        
        # timeout, still busy
        if busy_motors:
            return True, f"BUSY: motors {', '.join(busy_motors)}", busy_motors
        else:
            return True, "BUSY (unknown)", []




# ============================================================================
# COOLING FANS CONTROLLER
# ============================================================================

class CoolingFans:
    """Control for the fans according to the RPI temperature"""

    def __init__(self, verbose=False, settings_mgr=None):
        
        self.verbose = verbose
        self.settings_mgr = settings_mgr
        
        # load fans settings if available
        if self.settings_mgr:
            settings = self.settings_mgr.get()
            self.FANS_GPIO_PIN = settings.gpio.fans_gpio_pin
            self.FANS_PWM_FREQ = settings.fans.pwm_frequency
            self.FANS_PWM_DUTY_CYCLE = settings.fans.pwm_duty_cycle
            self.CPU_TEMP_FANS_ON = settings.fans.temp_on_celsius
            self.CPU_TEMP_FANS_HYST = settings.fans.temp_hysteresis_celsius
            self.CPU_TEMP_CHECK_INTERVAL_S = settings.fans.check_interval_s
                
        else:
            # fallback defaults
            self.FANS_GPIO_PIN = 19              # gpio pin controlling the pwm to the transistor's base
            self.FANS_PWM_FREQ = 100             # pwm frequency (higher frequency are more noisy)
            self.FANS_PWM_DUTY_CYCLE = 0.75      # pwm for the fans, to get enouf cooling yet limiting air noise
            self.CPU_TEMP_FANS_ON = 65.0         # temperature (Celsius) to swith the fans on
            self.CPU_TEMP_FANS_HYST = 5.0        # temperature histeresys (Celsius), to swith the fans off
            self.CPU_TEMP_CHECK_INTERVAL_S = 15  # period to check the RPI cpu temperature


        if self.verbose:
            print(f"Thermal control activated (Threshold: {self.CPU_TEMP_FANS_ON}°C)")
        
        self.fan = PWMOutputDevice(self.FANS_GPIO_PIN, frequency=self.FANS_PWM_FREQ)
        self.last_cpu_temp_check = time()
        self.fans_control()
    

    def get_cpu_temp(self):
        with open("/sys/class/thermal/thermal_zone0/temp", "r") as f:
            # the file hold the CPU temp in millidegrees (ie 45000 = 45.0 degrees)
            return float(f.read()) / 1000.0
    
    
    def fans_control(self):
        now = time()
        if now - self.last_cpu_temp_check > self.CPU_TEMP_CHECK_INTERVAL_S:
            
            temp = self.get_cpu_temp()
            if temp > self.CPU_TEMP_FANS_ON:
                if self.fan.value == 0:
                    if self.verbose:
                        print(f"CPU Temp: {temp:.1f}°C  swith-on the fans")
                    self.fan.value = self.FANS_PWM_DUTY_CYCLE
            
            elif temp < self.CPU_TEMP_FANS_ON - self.CPU_TEMP_FANS_HYST:
                if self.fan.value > 0:
                    if self.verbose:
                        print(f"CPU Temp: {temp:.1f}°C  swith-off the fans")
                self.fan.value = 0
            
            self.last_cpu_temp_check = now







# ============================================================================
# BALANCE CONTROLLER (All Integers)
# ============================================================================

@dataclass
class MotorAngles:
    """Holds the three motor angles as integers (tenths of degrees)."""
    A: int  # angle in tenths of degrees (i.e. 900 = 90.0°)
    B: int
    C: int

# ============================================================================
# BALANCE CONTROLLER ( PID close to center otherwise PD )
# ============================================================================
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

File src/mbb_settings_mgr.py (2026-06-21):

"""
Andrea Favero 20260607

MirrorBallBot (MBB), an alternative ball balance robot


More info at:
  https://github.com/AndreaFavero71/mirrorballbot
  https://www.instructables.com/MirrorBallBot-MBB-An-Alternative-Ball-Balancing-Ro/

Code for centralized Settings Manager




MIT License

Copyright (c) 2026 Andrea Favero

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
__version__ = "0.0.3"

from dataclasses import dataclass, field, asdict, fields, is_dataclass
from typing import Optional, List, Dict, Any, Union
from time import time, ctime
import shutil
import json
import os


# ============================================================================
# TYPE CONVERSION UTILITIES
# ============================================================================

def convert_value_to_type(value: Any, target_type: type) -> Any:
    """
    Convert a value to the target type with intelligent type coercion.
    
    Handles:
    - Boolean conversion from string/bool/int
    - Numeric conversions (int, float)
    - String conversions
    - List/dict preservation
    """
    if value is None:
        return None
    
    # handle boolean specially (JSON true/false, string "True"/"False", int 0/1)
    if target_type == bool:
        if isinstance(value, bool):
            return value
        if isinstance(value, str):
            return value.lower() in ('true', '1', 'yes', 'on')
        if isinstance(value, (int, float)):
            return bool(value)
        return False
    
    # handle numeric types
    if target_type == int:
        try:
            return int(float(value))  # Convert through float to handle scientific notation
        except (ValueError, TypeError):
            return 0
    
    if target_type == float:
        try:
            return float(value)
        except (ValueError, TypeError):
            return 0.0
    
    # handle string
    if target_type == str:
        return str(value)
    
    # handle lists and dicts (preserve as-is or convert from string)
    if target_type in (list, dict):
        if isinstance(value, target_type):
            return value
        # Try to parse JSON if it's a string
        if isinstance(value, str):
            try:
                return json.loads(value)
            except json.JSONDecodeError:
                return target_type()  # Return empty container on failure
        return target_type()
    
    # default: return as-is
    return value



def merge_dataclass(target: Any, source_dict: Dict[str, Any], strict: bool = False) -> Any:
    """
    Recursively merge a dictionary into a dataclass instance.
    
    Args:
        target: The target dataclass instance to update
        source_dict: Dictionary with new values
        strict: If True, only update fields that exist in target
    
    Returns:
        Updated target instance
    """
    if not is_dataclass(target):
        return target
    
    # get all field names and their types
    field_info = {f.name: f.type for f in fields(target)}
    
    for key, value in source_dict.items():
        if strict and key not in field_info:
            continue
        
        if key in field_info:
            field_type = field_info[key]
            
            # handle nested dataclasses
            if is_dataclass(field_type) and isinstance(value, dict):
                current_value = getattr(target, key, None)
                if current_value is None:
                    # create new instance if field doesn't exist
                    current_value = field_type()
                setattr(target, key, merge_dataclass(current_value, value, strict))
            else:
                # convert and set value
                converted_value = convert_value_to_type(value, field_type)
                setattr(target, key, converted_value)
    
    return target



# ============================================================================
# SETTINGS DATA CLASSES
# ============================================================================

@dataclass
class HardwareSettings:
    platform_diameter_mm: int = 220        # usable diameter (platform diameter - support)
    ball_diameter_mm: int = 30             # rough ball size, helping the auto HSV calibration to exclude noise
    camera_focus_distance_m: float = 0.4   # camera distance: camera to mirror + mirror to platform (once levelled)
    camera_resolution: Dict[str, int] = field(default_factory=lambda: {"width": 352, "height": 352})



@dataclass
class HomingSettings:
    speed_freq: int = 800
    sg_k_factor: int = 45
    sg_shifts: Dict[str, int] = field(default_factory=lambda: {"A": 0, "B": -5, "C": 0})



@dataclass
class BalanceSettings:
    steps_from_home: int = 220
    shifts: Dict[str, int] = field(default_factory=lambda: {"A": 6, "B": 10, "C": -6})



@dataclass
class MotorSettings:
    reverse: bool = False
    full_steps_per_rev: int = 200
    microsteps: int = 8
    max_speed: int = 65480
    min_speed: int = 5000
    base_speed: int = 55000
    positioning_speed: int = 15000  # speed for precise positioning moves
    homing: HomingSettings = field(default_factory=HomingSettings)
    balance: BalanceSettings = field(default_factory=BalanceSettings)

    @property
    def step_angle_tenths(self) -> float:
        """Calculate step angle in tenths of degrees."""
        return 10.0 * 360.0 / (self.full_steps_per_rev * self.microsteps) 



@dataclass
class ControllerSettings:
    target_cycle_time_ms: int = 60
    balance_angle_tenths: int = 900
    max_tilt_tenths: int = 400
    deadzone_tenths: int = 50
    deadzone_counter_thr: int = 15
    integral_zone_tenths: int = 400
    max_integral: int = 3000



@dataclass
class PIDSettings:
    kp: float = 1.3
    ki: float = 0.0
    kd: float = 1.0



@dataclass
class CurrentSettings:
    """Stepper motor current control settings."""
    irun: int = 31          # Run current when moving (0-31, 0=3%, 31=100%)
    ihold: int = 11         # Holding current when stopped (0-31, 0=3%, 31=100%)
    tpowerdown: int = 20    # Delay from standstill to current reduction (2-255, 0.5~5.5s)



@dataclass
class VisionSettings:
    hsv_lower: List[int] = field(default_factory=lambda: [0, 140, 181])
    hsv_upper: List[int] = field(default_factory=lambda: [9, 237, 247])



@dataclass
class FansSettings:
    enabled: bool = True
    pwm_frequency: int = 100
    pwm_duty_cycle: float = 0.75
    temp_on_celsius: float = 65.0
    temp_hysteresis_celsius: float = 5.0
    check_interval_s: int = 15



@dataclass
class PathsSettings:
    square_side_mm: int = 100
    circle_radius_mm: int = 70
    infinity_size_mm: int = 100
    triangle_side_mm: int = 100
    line_length_mm: int = 120
    tolerance_mm: int = 40
    settle_time_ms: int = 400
    repeats: int = 3
    speed_mm_per_s: float = 150.0



@dataclass
class DisplaySettings:
    frame_skip: int = 10
    video_update_interval_ms: int = 66
    status_update_interval_ms: int = 500
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

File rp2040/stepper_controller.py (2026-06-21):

"""
Andrea Favero 20260605

MirrorBallBot (MBB), a robot seeing through a mirror

More info at:
  https://github.com/AndreaFavero71/mirrorballbot
  https://www.instructables.com/MirrorBallBot-MBB-An-Alternative-Ball-Balancing-Ro/


MIT License
Copyright (c) 2026 Andrea Favero
"""

from time import ticks_diff, ticks_ms, ticks_us, sleep_ms,  sleep_us
from rp2 import PIO, StateMachine, asm_pio, asm_pio_encode
from shared_variables import shared_variables
from machine import Pin, reset
from TMC_2209_driver import *



class StepperController:
    
    # Bit position constants for status bitmask
    # These allow multiple states to be represented simultaneously in a single byte
    BIT_ENABLED   = 0  # 1 << 0 = 1   - Motor driver powered on
    BIT_MOVING    = 1  # 1 << 1 = 2   - Rotor currently turning
    BIT_HOMED     = 2  # 1 << 2 = 4   - At reference position
    BIT_BUSY      = 3  # 1 << 3 = 8   - Executing command (moving OR waiting for sync)
    BIT_STALL     = 4  # 1 << 4 = 16  - Stall/overcurrent detected
    BIT_ERROR     = 5  # 1 << 5 = 32  - Error state (thermal, overcurrent, etc)
    BIT_HOMING    = 6  # 1 << 6 = 64  - Homing procedure active
    BIT_RETRACT   = 7  # 1 << 7 = 128 - Retracting from home (sub-phase of homing)
    
    # Predefined status masks for common conditions (for convenience)
    MASK_READY_FOR_COMMAND   = (1 << BIT_ENABLED)  # Enabled (not busy check must be done separately)
    MASK_ACTIVE_MOVEMENT     = (1 << BIT_MOVING) | (1 << BIT_BUSY)
    MASK_HOMING_IN_PROGRESS  = (1 << BIT_HOMING) | (1 << BIT_BUSY)
    MASK_ERROR_STATES        = (1 << BIT_STALL)  | (1 << BIT_ERROR)

    _instance = None

    def __new__(cls, *args, **kwargs):
        if cls._instance is None:
            cls._instance = super().__new__(cls)
            cls._instance._init()
        return cls._instance

    
    
    def _init(self, reverse=False, ms=0, printout=True):
        # reverse: use True to reverse the stepper direction (solving wiring issue), otherwise False
        # ms: microstepping, from 0 to 3
        
        self.reverse = reverse             # flag to reverse the stepper direction (reverse==True) if wiring issues
        self.ms = ms                       # integГЁr reppresenting the microstep (0=1/8, 1=1/32, 2=1/64 and 3=1/16)
        self.printout = printout           # flag to print some data to the terminal for debug purpose  
        print("\n[core 0] Uploading stepper_controller ...")
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

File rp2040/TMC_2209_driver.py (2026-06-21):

"""
This code is a small extract of a much larger driver for TMC 2209 stepper driver.
In this implementation are only kept the StallGuard related functions.

Acknowledgements:
Many thanks to Chr157i4n for making that exstensive TMC_2209 library.
Many thanks to anonymousaga for his adaptation for Raspberry Pi Pico.


Original file: TMC_2209_StepperDriver.py

Source: https://github.com/troxel/TMC_UART
Source: https://github.com/Chr157i4n/TMC2209_Raspberry_Pi
Source: https://github.com/kjk25/TMC2209_ESP32
Source: https://github.com/anonymousaga/TMC2209_RPI_PICO

Copyright (c) 2020 troxel
Copyright (c) 2014 The Python Packaging Authority (PyPA)
Copyright (c) 2014 Mapbox

Modified by: Andrea Favero (07/06/2025)

Licensed under the GNU General Public License v3.0

"""



from TMC_2209_uart import TMC_UART
from machine import Pin


#-----------------------------------------------------------------------
# TMC_2209
#
# this class has two different functions:
# 1. change setting in the TMC-driver via UART
# 2. move the motor via STEP/DIR pins
#-----------------------------------------------------------------------
class TMC_2209:
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

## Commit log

2026-06-21 Added fully 3D printable version, and other improvements
    Added:
    • Fully 3D printable version, to the wooden base model
    • Project difficulty chapter
    • Calibration chapter
    • Modules connection diagram.
    • Current management (IRUN, IHOLD, TPOWERDOWN)
    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
    [Arm_1.stl, Arm_1.stp, Arm_2.stl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]
2026-08-23 Revision post building the fully 3D printable version
    CAD rev. 10
    Instructions Rev 2
    Code: Solved bug on free-path recording (bug introduced with previous release)
    [Arm_1.stl, Arm_1.stp, Arm_2.stl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]
2026-08-23 Revise README with updates and Fully 3D version picture
    Updated README.md to reflect changes in manual length, RAM size for Raspberry Pi 4, added image of the 3D printable version.
2026-08-24 Fix 3D printing instructions for wooden base
2026-09-06 3D files rev11, improved robot start-up, Instructions manual rev3
    3D files: Rationalized files between the two versions. Added 3D printable labels for personalization. Improved assembly.
    Code: The GUI shows up prior camera setting and robot start-up. Video stream before lifting the platform.
    Instruction manual: Corrected errors, added printing time and other info, overall improvement.
    [Arm_1.stl, Arm_1.stp, Arm_2.stl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]
